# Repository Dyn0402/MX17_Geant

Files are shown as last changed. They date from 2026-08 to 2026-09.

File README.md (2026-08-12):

# MX17 Micromegas Simulation

Geant4 simulation of the MX17/X17 n-TOF Micromegas detector. Multiple geometry
modes support detector development, material budget studies, and calibration.

## Simulation modes

| Mode | `-m` flag | Description |
|---|---|---|
| Vacuum | `vacuum` | Micromegas in vacuum, optional Al upstream shielding |
| Full experiment | `full` | He-3 target → air → MM → PCB → scint wall → 2× LS |
| Sr-90 calibration | `sr90` | Same stack but without He-3 target |
| Sr-90 no-MM | `sr90nomm` | Source in air directly to scint wall → LS (no MM/PCB) |
| LS calibration | `lscalib` | Bare source gun → air → **1 LS layer only** |
| Back scint calibration | `backscintcalib` | Bare source gun → air → **1 back scint bar only** |

The two calibration modes (`lscalib`, `backscintcalib`) study each detector in
isolation with a bare source and are designed to be run with the Sr-90/Y-90
beta spectrum sampled at the gun (`--spectrum`).

## Detector geometry

The MM module (window → support plate) has **one description**,
[`shared/MX17ModuleGeometry.hh`](shared/MX17ModuleGeometry.hh), consumed by
this sim and by `../MX17_Full_Geant`. The default is the **as-built** module
derived from the mechanical CAD + hardware knowledge
([`design/GEOMETRY_FROM_CAD.md`](design/GEOMETRY_FROM_CAD.md),
[`design/GEOMETRY_IMPLEMENTATION_NOTES.md`](design/GEOMETRY_IMPLEMENTATION_NOTES.md);
remaining assumptions in [`design/NEEDED_INPUTS.md`](design/NEEDED_INPUTS.md)):

- **Window**: 60 µm aluminized mylar, 440×440, bulged by the gas overpressure
  (terraced dome, default 8 mm sag ≈ Hencky at ~3 mbar, `--bulge-front`)
- **Window flange**: 5 mm Al ring (440/400.2) = 5 mm gas gap before the cathode
- **Drift**: Cu-clad kapton cathode (406²), 30.000 mm gap set by the Al gas
  frame (440/410), 4× 1.62 mm field-cage PCBs lining the aperture
- **Mesh**: woven SS 19/48 µm → 38 µm effective-density slab (fill 0.223);
  bulk pillars (Ø0.6 mm, 85×85 grid at 4.68 mm) stand in the amplification gap
- **Resistive layer**: 515 discrete ESL strips, 550 µm wide on a 0.8 mm pitch,
  **10 µm** thick over 412²; the 250 µm inter-strip grooves are chamber gas and
  are scored as `AmpGas` (they add 2.0 % of the amp-gas energy deposit)
- **Readout board**: 1.70 mm single body (mesh + 150 µm amp + 10 µm ESL +
  laminate), 470², offset (+15,+15) from the active axis; copper = the five
  physical gerber layers (guard ring, pads, Y strips, X strips, fan-out),
  density-scaled by their measured coverage (`scripts/gerber/analyze_cu_coverage.py`).
  Each layer is built as **two zones** — inside and outside the 399.36 mm
  active window — because the copper is very unevenly distributed: the pad
  layer is 0.76 covered inside the active area and 0.057 outside, so a single
  board-wide average (0.564) would put ~26 % too little copper where the beam
  passes and ~10× too much at the edges. Zoning costs no CPU.
- **Backing**: 5 mm rohacell + 25 µm aluminized mylar + **8 mm Al support
  plate with a 402 mm aperture** concentric with the 399.36 mm active area
- **M1 front-end cards**: 2× per connector edge, flat on the drift side of
  the board edge and straddling it (6.6 mm envelope: 6 gerber Cu layers + FR4)

> **The 399.36 mm active window is metallised, not efficient (2026-08-11).**
> The strip plane is passivated over ~19 mm at each end of **Y**, so the
> efficient area is 399.4 × 359.9 mm, not square. Measured twice (June cosmic
> bench vs the M3 telescope; n_TOF beam run_79 paired clusters —
> `nTof_x17/ntof_active_area/report.html`). Not modelled here on purpose: this
> sim runs at chosen impact points. **Any Y sweep or acceptance number must
> apply the band.** See `design/GEOMETRY_FROM_CAD.md`.

### Real readout pattern (default; `--homogenized-readout` to disable)

The three signal copper layers are built as the **real 512 × 512 pattern** read
off the production gerbers: 0.68 mm square pads on L4, and Ø0.50 mm dots +
0.098 mm bus traces on the L5/L6 X-Y track layers, all on the gerber-exact
0.78 mm pitch. The **ESL resistive layer** is likewise built as 515 discrete
550 µm strips on the 0.8 mm pitch, inside a gas-filled envelope — so the 250 µm
inter-strip grooves are real chamber gas, not reduced-density paste. Total ESL
mass is unchanged (515 × 0.550 / 412 = 0.6875, exactly the old scale factor).

The groove cells are named `AmpGas`, so groove ionisation is scored as
amplification signal: they are only 10 µm deep at the bottom of a 150 µm gap,
so the amplification field runs through them essentially undisturbed. They add
2.0 % of the amp-gas energy deposit.

> ⚠️ **If you consume `ClusterTree`**: the groove cells are thin, so Geant4
> forces short steps and each writes its own row. The grooves are 2.0 % of
> amp-gas *energy* but 21.7 % of amp-gas *rows*. Sum `edep` or `nPrimary` —
> never count rows as a proxy for ionisation. (`nPrimary` is safe: the sub-W
> remainder is carried probabilistically, so nothing is lost to segmentation.)

L3 (guard ring) and L7 (fan-out) have irregular artwork and stay as the
two-zone density-scaled sheets.

Both grids are perfectly regular, so they are built with `G4PVReplica` (two
nested levels for the copper, one for the strips). The whole 786432-feature
copper pattern plus 515 ESL strips costs **17 extra volumes**, not 786943
placements, and cell lookup stays O(1) index arithmetic:

| | volumes | total CPU, 100k sr90 events | max RSS |
|---|---|---|---|
| `--homogenized-readout` | 7342 | 27.0 s | 582 MB |
| patterned (default) | 7359 | 28.0 s | 579 MB |

So the full pattern costs about **+3–4 % of total CPU** and no extra memory.
Removing the fixed ~13 s of startup overlap-checking, the tracking-only cost is
roughly +9 %, most of it from the resist strips rather than the copper (the ESL
is 100 µm thick against 26 µm per Cu layer, and its envelope adds gas/solid
boundaries). Treat these as ±3 % — they were measured as user CPU time,
min-of-4, on a machine with other jobs running.

It is cheap because the patterned layers total ~180 µm of a ~45 mm stack, so
few steps land there — not because the pattern is approximated.

**When you can turn it off**: the signal copper sits *downstream of both gas
gaps*, so for anything scored in the gas the homogenized zones give
essentially the same answer. The resist strips are the part that could matter
even for gas scoring, since the ESL bounds the amplification gap. The pattern
would also get relatively more expensive for tracks at shallow incidence,
which cross many cells per layer.

`--legacy-geometry` is never patterned regardless of these flags, so it stays
bit-identical to the pre-2026-08 output (checked with `scripts/tree_digest.py`).

`--legacy-geometry` restores the pre-2026-08 uniform-slab stack (bit-identical
to the old build). Model figures live in `design/figures/` and regenerate with
`python scripts/model/plot_mx17_model.py`; the cross-section/3D/plan figures
render the **true constructed geometry** from `design/mx17_geometry.json`
(refresh it after geometry changes: `mm_sim -m sr90 --dump-geometry
design/mx17_geometry.json`), while the board/peel figures render the
production gerbers directly.

### The layer stack

Generated from the header — regenerate with `python3 scripts/stack_table.py`,
and `--check` fails if it has drifted from the geometry.

<!-- BEGIN STACK TABLE (generated by scripts/stack_table.py) -->

| Layer | Material | Thickness | G4 volume | Note |
|---|---|---|---|---|
| Gas window | Mylar (PET) | 60 µm | `GasWindow_Mylar` |  |
| Gas window coat | Aluminium | 0.1 µm | `GasWindow_Al` | drift side |
| Window→cathode gas | chamber gas | 5 mm | `WindowGapGas` | set by the 5 mm flange |
| Drift cathode | Kapton | 50 µm | `DriftCathode_Kapton` |  |
| Drift cathode Cu | Copper | 9 µm | `DriftCathode_Cu` | cladding, drift side |
| **Drift gas** ★ | **chamber gas** | 29.991 mm | **`DriftGas`** | kapton back → mesh front = 30.000 mm |
| Micromesh | Stainless steel | 38 µm | `Micromesh` | woven 19/48 µm, fill 0.223 |
| **Amp gas** ★ | **chamber gas** | 150 µm | **`AmpGas`** | bulk pillars Ø0.6 mm on a 4.68 mm grid stand in it |
| Resistive layer (ESL) | C/acrylic paste | 10 µm | `ResistLayer` + `ESLStrip` | 515 strips, 550 µm on 0.8 mm; grooves are `AmpGas` |
| Coverlay kapton | Kapton | 50 µm | `PCB_Kapton` | **the ESL⇄pad insulator** — see the note below |
| Lamination adhesive | Acrylic | 18.8 µm | — *not placed* | response-model estimate, not in the header |
| Cu L3 guard ring | Copper | 26 µm | `PCB_Cu_3` | density-scaled |
| FR4 under L3 | Epoxy-glass | 264.4 µm | `PCB_FR4_3` | **residual** of the CAD 1.70 mm board |
| Cu L4 pads | Copper | 26 µm | `PCB_Cu_4` | real 512×512 pattern |
| FR4 under L4 | Epoxy-glass | 264.4 µm | `PCB_FR4_4` | **residual** of the CAD 1.70 mm board |
| Cu L5 Y strips | Copper | 26 µm | `PCB_Cu_5` | real 512×512 pattern |
| FR4 under L5 | Epoxy-glass | 264.4 µm | `PCB_FR4_5` | **residual** of the CAD 1.70 mm board |
| Cu L6 X strips | Copper | 26 µm | `PCB_Cu_6` | real 512×512 pattern |
| FR4 under L6 | Epoxy-glass | 264.4 µm | `PCB_FR4_6` | **residual** of the CAD 1.70 mm board |
| Cu L7 fan-out | Copper | 26 µm | `PCB_Cu_7` | density-scaled |
| FR4 under L7 | Epoxy-glass | 264.4 µm | `PCB_FR4_7` | **residual** of the CAD 1.70 mm board |
| Rohacell 51 | PMI foam | 5 mm | `PCB_Rohacell` |  |
| Backing mylar | Mylar (PET) | 25 µm | `PCB_BackMylar` | aluminized |
| Backing Al | Aluminium | 0.1 µm | `PCB_AlFoil` |  |
| Support plate | Aluminium | 8 mm | `SupportPlate_Al` | 402 mm aperture |

Depths are in beam order from the window front face; the stack totals **49.835 mm** to the back of the support plate (the readout board body is exactly the CAD **1.700 mm** from mesh front to laminate back). Board **470²**, **399.36 mm** readout window. ★ = scored volume.

**Two cautions about the bottom half of this table.**

*The FR4 is a residual, not a measurement.* The CAD gives one 1.70 mm number for the whole board body; everything we think we know is subtracted and the remainder is divided equally over the five laminate layers. So changing any other layer silently changes the FR4 — when the ESL went 100 → 10 µm the filler went 246.4 → 264.4 µm. A fab stackup drawing would turn this into a real number (`design/NEEDED_INPUTS.md` §6).

*Do not read the ESL⇄pad capacitance off this ordering.* Taken literally the table puts a 264 µm FR4 layer between the coverlay and the pad copper, because the guard-ring layer above the pads is placed first — and that layer has **zero** copper inside the active window, so the separation there is an artifact of the equal-division residual above, not geometry anyone measured. The response model instead takes the physically motivated adjacency for a resistive Micromegas: the ESL sits on the coverlay kapton, which is laminated straight onto the pads. That is the stack `response/solver/wpot.py` solves, and the ~19 µm of adhesive is 29 % of the insulator it sees. The two models disagree here and the disagreement is unresolved; it does not matter for material budget (order barely matters for energy deposit) and it matters completely for the induced signal. The same missing fab drawing settles both.

<!-- END STACK TABLE -->

Everything downstream of the module is unchanged:

- **He-3 target**: r = 1.5 cm, L = 8 cm, 300 bar; Al (0.5 mm) + CFRP (0.9 mm) capsule
- **Trigger scint wall**: 200 µm BlackMylar tape + 3 mm PVT + 50 µm Al foil
- **LS stack**: 2 mm CFRP wall + 600 µm inner CFRP liner + 40 µm Al liner + **2 cm LAB** × 2 layers
- **Back scint bar**: 30×20×2 cm PVT, wrapped in 20 µm Al foil + 200 µm BlackMylar tape

## Command-line options

```
-m <mode>          vacuum | full | sr90 | sr90nomm | lscalib | backscintcalib
-p <particle>      electron | gamma | positron | proton | muon | ...
-e <energy>        Particle energy [MeV]  (ignored when --spectrum is set)
-n <nevents>       Number of events
-g <gas>           ArIso | ArCF4 | ArCO2 | HeEth | NeCF4 | PureAr | ...
-o <output>        Output file base name
-s <seed>          Random seed
-t <nthreads>      MT threads (default: 1)
-c <mm>            CFRP wall thickness [mm] (default: 2.0)
--spectrum <csv>   Sample electron energies from Sr-90/Y-90 spectrum CSV
                   (two whitespace-separated columns: energy_MeV  probability)
--src-dist <mm>    Source-to-detector air gap [mm] (lscalib/backscintcalib, default: 100)
--bulge-front <mm> Front-window overpressure dome sag (default: 8, 0 = flat)
--legacy-geometry  Pre-2026-08 uniform-slab MM module (old stack, bit-identical;
                   never patterned, regardless of the flags below)
--homogenized-readout  Density-scaled copper sheets + ESL slab instead of the
                   default real pattern (~3 % faster; see "Real readout pattern")
--patterned-readout Explicitly request the real pattern (this is the default)
--dump-geometry <f> Write the constructed geometry to JSON and exit (feeds
                   scripts/model/plot_mx17_model.py so figures show the true geometry)
-v                 Verbose
-h                 Help
```

## Output columns

**All modes** (`_events.csv`): `eventID, edepDrift_eV, edepAmp_eV, ...`

**Full / Sr90 modes** (extra columns):
```
edepHe3Gas, edepMylar, edepCathode, edepMicromesh,
edepPCB, edepPCBKapton, edepPCBCu, edepPCBFR4, edepPCBRohacell, edepPCBAlFoil,
edepScintWall, edepScintTape, edepScintAlFoil,
edepLS1_eV, edepLS2_eV, edepLSCFRP_eV,
primInHe3Gas, primInPCB, primInScintWall, primInLS1, primInLS2, primInLSCFRP5
```

**kLSCalib / kBackScintCalib** (extra columns):
```
primaryKE_MeV,          ← sampled beta energy
edepLS1_eV,             ← energy in LAB layer  (lscalib)
edepLSCFRP_eV,          ← energy in LS structural walls (lscalib)
primInLS1,
edepBackScint_eV,       ← energy in PVT bar  (backscintcalib)
primInBackScint
```

## Building on lxplus

```bash
ssh lxplus.cern.ch
source scripts/setup_lxplus.sh
bash scripts/build.sh
```

The binary is written to `build/mm_sim`.

## Running on lxplus with HTCondor

> **AFS vs EOS rule**: HTCondor's submit file (`executable`, `log`, `output`, `error`)
> must reference AFS paths. Simulation output files are written by the job script and
> may live on EOS. Each submit script enforces this automatically:
> `--jobdir` (AFS, default `~/condor/...`) controls job control files;
> `--outdir` (EOS) controls where ROOT/CSV output is written.

### Sr-90 calibration (full material stack, energy sweep)

```bash
python scripts/submit_condor_sr90.py \
    --exe /eos/home-d/dneff/sim/mm_sim \
    --outdir /eos/home-d/dneff/sim/sr90_out \
    --mode sr90nomm
# jobdir defaults to ~/condor/mx17_geant_sr90 (AFS)
```

### LS calibration (liquid scintillator only, Sr-90 spectrum sampling)

```bash
python scripts/submit_condor_lscalib.py \
    --exe      /eos/home-d/dneff/sim/mm_sim \
    --spectrum /eos/home-d/dneff/sim/sr90_calibration/Sr90_Y90_Beta_Spectrum.csv \
    --outdir   /eos/home-d/dneff/sim/lscalib_out \
    --mode ls --njobs 20 --nevents 100000
# jobdir defaults to ~/condor/mx17_lscalib (AFS)
```

### Back scint calibration (plastic scint only, Sr-90 spectrum sampling)

```bash
python scripts/submit_condor_lscalib.py \
    --exe      /eos/home-d/dneff/sim/mm_sim \
    --spectrum /eos/home-d/dneff/sim/sr90_calibration/Sr90_Y90_Beta_Spectrum.csv \
    --outdir   /eos/home-d/dneff/sim/backscint_out \
    --mode backscint --njobs 20 --nevents 100000
```

### Merging job outputs

```bash
# ROOT (if built with USE_ROOT)
hadd lscalib_all.root lscalib_out/ls_calib_job*.root

# CSV
head -1 lscalib_out/ls_calib_job000_events.csv > ls_merged.csv
tail -n +2 -q lscalib_out/ls_calib_job*_events.csv >> ls_merged.csv
```

### Full experiment (X17 physics, energy sweep)

```bash
python scripts/submit_condor_full.py \
    --exe /eos/home-d/dneff/sim/mm_sim \
    --outdir /eos/home-d/dneff/sim/full_out
```

## Analysis

### LS / back scint calibration

```bash
# After merging job outputs:
python ls_calibration/analyze_ls_calibration.py \
    --indir /path/to/merged --mode ls   --outpdf ls_calib.pdf

python ls_calibration/analyze_ls_calibration.py \
    --indir /path/to/merged --mode backscint --outpdf backscint_calib.pdf
```

Output PDF contains:
- Edep spectrum (all events + zoom)
- Mean edep and efficiency vs sampled beta energy
- 2D: beta energy vs detector edep
- Summary page with spectrum-integrated statistics

### Sr-90 calibration analysis (full material stack)

```bash
python sr90_calibration/analyze_sr90_calibration.py \
    --indir /path/to/sr90nomm/csvs --prefix sr90nomm
```

### Full experiment analysis

```bash
python scripts/analyze_full_experiment.py \
    --indir /path/to/full/csvs --gas ArIso --prefix full
```

## Calibration geometry details

### kLSCalib

```
Gun position (z = −totalZ/2)
↓  [100 mm air, configurable via --src-dist]
LS_CFRP_1       2 mm   CFRP structural front wall
LS_InnerCFRP_1  600 µm inner CFRP liner
LS_Al_1         40 µm  Al liner
LiqScint_1      20 mm  LAB liquid scintillator  ← scored: edepLS1
LS_InnerCFRP_2  600 µm
LS_Al_2         40 µm
LS_CFRP_2       2 mm   CFRP structural back wall
```

### kBackScintCalib

```
Gun position (z = −totalZ/2)
↓  [100 mm air, configurable via --src-dist]
BackScintWrap_Tape1   200 µm  black mylar tape
BackScintWrap_Al1      20 µm  Al foil
BackScint              20 mm  PVT plastic scintillator  ← scored: edepBackScint
BackScintWrap_Al2      20 µm
BackScintWrap_Tape2   200 µm
```

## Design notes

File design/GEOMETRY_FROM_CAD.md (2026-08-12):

# MX17 as-built geometry vs. the Geant4 models

Derived from the mechanical CAD on 2026-08-06. This is a reference for updating
`src/DetectorConstruction.cc`; it states what the CAD says, what the two
simulations said at the time, and where they disagreed.

> **Status 2026-08-06 (later the same day):** the as-built geometry below is
> now implemented in `shared/MX17ModuleGeometry.hh` (consumed by both sims);
> the ❌ marks in the side-by-side table describe the *pre-upgrade* models and
> are kept as the historical record. See
> [`GEOMETRY_IMPLEMENTATION_NOTES.md`](GEOMETRY_IMPLEMENTATION_NOTES.md) for
> what was done and [`NEEDED_INPUTS.md`](NEEDED_INPUTS.md) for the remaining
> assumptions. Model figures: `design/figures/mx17_*.png`
> (`scripts/model/plot_mx17_model.py`).
>
> **Correction:** discrepancy 1 below originally claimed the 8 mm support
> plate is solid. That was a parser error — see the rewritten entry.

## Sources

| Source | Location | Notes |
|---|---|---|
| Full detector CAD | `~/x17/mx17_cad/MX17 2026 v1.3 05 06 2026.stp` | 14 MB, Solid Edge → STEP AP214, exported 2026-06-05. 23 products, 72 placed instances. **One** MX17 module. |
| PCB fabrication data | `design/gerbers/` (in this repo) | Readout gerbers; `DFS3498A_gasframe.gbr` independently confirms the frame aperture. |
| LS vessel | `~/x17/LS_Stuff/LS X17.step` | Shapr3D, separate file. Already modelled in `MX17_Full_Geant`. |
| Scintillator clamps | `~/x17/mx17_cad/assembly of scintillators.stp` | 4× `pince scintillateur` only; its `LS X17` children are empty placeholders. |
| Trigger paddle / PMT | `~/x17/mx17_cad/paletta_e_supportoPM.stp` | `paletta` 200×24×492, `supporto_XP2982_v2` (Photonis XP2982). Not part of the MM stack. |

## As-built stack

Along the beam axis, entrance first. Dimensions in mm, measured from the solids.

| Z range | Part | Transverse | Thickness |
|---|---|---|---|
| 307.897–307.957 | Mylar window | 440 × 440 | 0.060 |
| 302.897–307.897 | **window flange** (Al ring) | 440 outer, 400.2 aperture | 5.000 |
| 302.847–302.897 | Kapton drift cathode | 406 × 406 | 0.050 |
| 272.847–302.847 | **Alu gas flange** (the frame) | 440 outer, **410.0 aperture**, 15 mm wall | **30.000** |
| 272.847–304.447 | 4× drift field PCB (field cage) | 408.4 × 1.62, forming a 410 mm ring | 31.6 tall |
| 271.247–272.947 | PCB readout | 470 × 470 | 1.700 |
| 266.247–271.247 | rohacell | 470 × 470 | 5.000 |
| 258.247–266.247 | **Alu detector support** | 470 × 470, **402 × 402 through-aperture** | 8.000 |

Also present, outside the beam path: 4× `multi M1 PCB` (41 × 180 × 6.6) forming a
446 mm ring around the readout, the SHV/HV housing and covers, gas entry fittings,
geometer targets and fasteners.

Key derived numbers:

- **Drift gap = 30.000 mm exactly** — the Al frame *is* the spacer; its faces
  coincide with the readout PCB top and the Kapton cathode.
- **Frame aperture 410.0 mm** — cross-checked against `DFS3498A_gasframe.gbr`,
  whose routing outline runs ±205 mm. Two independent files agree.
- Window face to readout surface: **35.010 mm** (sim: 30.379 mm).
- Total module depth, Mylar front to Al support back: **49.710 mm** (sim: 35.983 mm).
- Material behind the gas, **on axis**: **6.70 mm** (1.70 PCB + 5.00 rohacell;
  the 8 mm Al plate has a 402 mm aperture clearing the active area) vs
  **5.604 mm** in both sims. Outside the aperture the plate adds its 8 mm.

## Side-by-side

`MX17_Geant` = this repo (`src/DetectorConstruction.cc`).
`MX17_Full_Geant` = `../MX17_Full_Geant/src/DetectorConstruction.cc`.
The two use **identical** MM and PCB layer constants; they differ only in
transverse face size and in that Full_Geant replicates the module across 4 arms.

| # | Feature | As-built (CAD) | MX17_Geant | MX17_Full_Geant |
|---|---|---|---|---|
| 1 | Mylar window | 60 µm, 440×440 | ❌ 40 µm | ❌ 40 µm |
| 2 | Window Al metallization | 🔶 absent from CAD | ✅ 0.1 µm | ✅ 0.1 µm |
| 3 | Window flange (Al ring, 5 mm) | present | ❌ absent | ❌ absent |
| 4 | Gas gap, window → cathode | 5.0 mm | ❌ absent | ❌ absent |
| 5 | Kapton drift cathode | 50 µm, 406×406 | ✅ 50 µm | ✅ 50 µm |
| 6 | Cu cathode cladding | 🔶 absent from CAD | ✅ 9 µm | ✅ 9 µm |
| 7 | **Drift gap** | **30.000 mm** | ✅ 30 mm | ✅ 30 mm |
| 8 | **Aluminium gas frame** | 440 out / 410 ap / 30 mm | ❌ absent | ❌ absent |
| 9 | Drift field-cage PCBs | 4× 408.4×1.62×31.6 | ❌ absent | ❌ absent |
| 10 | Micromesh | ⚠️ inside 1.7 mm board | ⚠️ 30 µm slab | ⚠️ 30 µm slab |
| 11 | Amplification gap | ⚠️ inside 1.7 mm board | ⚠️ 150 µm | ⚠️ 150 µm |
| 12 | Resistive paste | ⚠️ inside 1.7 mm board | ⚠️ 100 µm | ⚠️ 100 µm |
| 13 | Readout PCB body | 1.70 mm, 470×470 | ❌ 0.554 mm laminate | ❌ 0.554 mm laminate |
| 14 | Rohacell | 5.0 mm, 470×470 | ✅ 5 mm | ✅ 5 mm |
| 15 | **Backing plate** | **8 mm Al ring, 402 mm aperture** | ❌ 50 µm Al foil | ❌ 50 µm Al foil |
| 16 | Front-end (multi M1) PCBs | 4× 41×180×6.6 | ❌ absent | ❌ absent |
| 17 | Transverse face | 440 (window) / 470 (PCB) | ⚠️ 400 × 400 | ⚠️ 380 × 340 |
| 18 | Copper readout segmentation | pads + X/Y strips | ❌ solid Cu sheets | ❌ solid Cu sheets |
| 19 | Material behind gas | 14.70 mm | ❌ 5.604 mm | ❌ 5.604 mm |
| 20 | Aluminized mylar behind rohacell | 🔶 absent from CAD | ❌ absent | ❌ absent |
| 21 | Front-window pressure bulge | n/a (CAD is unpressurized) | ❌ flat | ❌ flat |

✅ matches · ❌ disagrees · 🔶 real, but absent from the CAD · ⚠️ not determined
by the CAD, or approximated by choice

Rows 2, 6, 20 and 21 come from Dylan's knowledge of the hardware, not from the
files. The mechanical CAD models foils as plain solids and carries no
metallization or cladding, so its silence on rows 2 and 6 is not evidence of
absence — **the simulations are right there and must not be "corrected" toward
the CAD.** See [`GEOMETRY_IMPLEMENTATION_NOTES.md`](GEOMETRY_IMPLEMENTATION_NOTES.md) §2.

## Discrepancies, worst first

**1 — The 8 mm aluminium backing plate is missing (row 15).**
`Alu detector support modifié` is a 470 × 470 × 8 mm plate directly behind the
rohacell — **with a 402 × 402 mm square through-aperture** (plus ~100
bolt/fastener holes of r ≤ 2.5 mm at the periphery).

*Correction 2026-08-06:* this entry originally claimed the plate was "verified
solid". That was wrong — the first STEP parse missed the inner boundary loops
of the two Z-normal faces. Re-analysis of the face loops shows an inner
FACE_BOUND of 402 × 402 mm on both faces (a through-cut), offset (−15, −15) in
the part frame. Cross-registration with the readout gerbers
(`DFS3498A_activearea.gbr`: 399.36 mm active area flashed at the gerber
origin; copper extents centred (+15, +15)) shows the **aperture is concentric
with the active area** — 1.32 mm clearance per side — and it is the 470 mm
plates (readout PCB, rohacell, support plate) that sit offset (+15, +15) from
the active axis. Dylan confirmed the intent: the frame screws into the plate,
but there is no aluminium behind the active area.

So the plate does *not* block on-axis Sr-90 betas; it matters for the
periphery (frame-region scattering and anything outside the 402 mm square).
Both sims previously modelled this position as 50 µm of Al foil over the full
face — wrong in both directions at once.

**2 — Material behind the gas: 14.70 mm vs 5.604 mm (row 19).**
Even setting the Al plate aside, the readout board is a single 1.70 mm solid in
CAD where the sims build a 0.554 mm laminate of 4×(26 µm Cu + 100 µm FR4) plus
50 µm Kapton.

**3 — Missing 5 mm gas gap between window and cathode (row 4).**
The window flange is 5 mm thick with a 400.2 mm aperture; the Mylar sits on its
outer face, the Kapton on its inner face. The gap between them is open gas. Both
sims stack Mylar → Al → Kapton → Cu contiguously.

**4 — Mylar window 60 µm, not 40 µm (row 1).**

**5 — All lateral structure absent (rows 3, 8, 9, 16).**
The 30 mm Al frame ring, the 5 mm window flange ring, the field cage and the
front-end boards. Irrelevant for on-axis transmission; this is exactly the
material that governs peripheral scattering and frame-induced background.

## What the CAD does *not* settle

- **Materials.** STEP carries no material assignment. "Aluminium" for the frame,
  window flange and support plate comes from part names only.
- **Mesh, amplification gap, resistive paste.** Absent as separate solids — they
  are sub-mm bulk-process features folded into the 1.70 mm `PCB readout` body.
  The sims' separate layers are not contradicted; in reality they live inside
  that 1.7 mm. Do not add their thickness on top of the CAD numbers.
- **PCB internal stackup.** Copper and dielectric thicknesses are in neither the
  CAD nor the gerbers. The 26 µm / 100 µm values in the sims have no traced
  source. The gerbers do give in-plane segmentation: 0.68 mm pads on 0.78 mm
  pitch, 512 × 512 over a 399.36 mm active area, with 3 functional copper layers
  (pads, Y strips, X strips) — not the 4 uniform sheets both sims use.
- **The Y-edge passivation** (added 2026-08-11). The gerbers' 399.36 mm active
  area is the *metallised* region, and this sim builds exactly that, square. But
  the strip plane is **passivated over a ~19 mm band at each end of the Y
  coordinate**, so a particle landing there produces no collected charge at all
  — neither plane sees it. The efficient region is therefore
  **399.4 mm in X × 359.9 ± 1.8 mm in Y**, not square.

  Measured twice, agreeing to 1–2 mm: June 2026 cosmic bench against the M3
  telescope (all five chambers, `nTof_x17/common/mx17_active_area.py`), and
  n_TOF beam run_79 paired strip clusters with no external reference (chambers
  A/B/C, `nTof_x17/ntof_active_area/report.html`). The band is centred.

  **Likely mechanism, not measured:** `RESPONSE_SIM_PLAN.md` §1 records that the
  ESL resistive strips contact copper bus strips **at both y-ends of the active
  area and nowhere in between** (user, 2026-08-07). A dead band of the same
  width, at the same two ends, on the same coordinate, is what a covered bus
  termination would look like. That would explain why the passivation is on Y
  and not X, which is otherwise an odd asymmetry. Nobody has checked it against
  the gerbers — if the bus footprint is ~19 mm, this is closed.

  **This sim does not model it, deliberately.** The pad/strip structure here is
  the readout geometry and is validated as such; the passivation is a collection
  effect on top of it, and adding it would change the pad build for no gain in
  the response chain, which is run at chosen impact points rather than over a
  flood. **But any study that sweeps the impact point across the full Y range,
  or that quotes an area or an acceptance, has to apply the band itself.** In
  `MX17_Full_Geant` — where the sim *is* used for acceptance — it is applied,
  as `mm_size_v_cm = 36.0`.

## Method

Bounding boxes and placements were extracted with a purpose-written STEP parser.
Two traps, both of which produce plausible-looking wrong answers:

1. **Bounding boxes must use `VERTEX_POINT`s only.** Taking every
   `CARTESIAN_POINT` includes arc and fillet centres that lie far outside the
   solid — the gas frame measured 931 × 927 × 598 mm instead of 440 × 440 × 30.
2. **Assembly transform direction must be resolved, not assumed.** Match
   `REPRESENTATION_RELATIONSHIP.rep_1/rep_2` against the child product's own
   shape representation to decide which `ITEM_DEFINED_TRANSFORMATION` item is
   the child frame. With the convention reversed, the four field-cage PCBs
   scatter ~2 m apart instead of closing into their 410 mm square.

Sanity checks that passed: the four field-cage PCBs close into a 410.0 mm ring;
the four front-end boards close into a 446 mm ring; the frame aperture matches
the gerber gas-frame outline; all plate thicknesses come out as round numbers.

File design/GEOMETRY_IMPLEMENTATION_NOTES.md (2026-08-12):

# MX17 geometry — implementation brief

Companion to [`GEOMETRY_FROM_CAD.md`](GEOMETRY_FROM_CAD.md), which records the
as-built dimensions. This file is the **work order**: what to change, in what
order, and which numbers are still missing.

Written 2026-08-06. Items 2–5 come from Dylan's domain knowledge and correct or
extend what the CAD alone shows.

> **Status — implemented 2026-08-06.** All six tasks are done:
>
> - §1 merge: `shared/MX17ModuleGeometry.hh` is the single module description,
>   consumed by both repos (option A, relative-path include with a CMake
>   guard). Landed as a pure refactor first — fixed-seed runs of every mode in
>   both sims were verified **bit-identical** to the pre-refactor builds.
> - §2–§6 applied on top: 60 µm window, 5 mm flange gap, copper-clad cathode,
>   440/406/410/470 faces + rings + field cage + M1 cards, woven-mesh
>   effective-density slab (19/48 µm placeholder), 1.70 mm readout body,
>   aluminized-mylar back foil (25 µm assumed), 8 mm support plate, terraced
>   front-window bulge (8 mm sag ≈ Hencky at 3 mbar, `--bulge-front`).
>   `--legacy-geometry` restores the old stack.
> - The §6 "held back" item is resolved: the plate has a **402 mm aperture in
>   the STEP file** (the earlier "verified solid" reading was a parser error —
>   see `GEOMETRY_FROM_CAD.md`, discrepancy 1) so it is modelled as a ring and
>   does not stop on-axis betas.
> - Remaining assumptions moved to [`NEEDED_INPUTS.md`](NEEDED_INPUTS.md).
> - Python mirror + figures: `scripts/model/`, output in `design/figures/`.

## Task summary

| # | Task | Blocked on input? |
|---|---|---|
| 1 | Merge the two Geant4 detector descriptions into one source of truth | no |
| 2 | Correct the CAD reading: drift copper and window aluminization | no |
| 3 | Add the aluminized mylar behind the rohacell | **yes** — thicknesses |
| 4 | Port the gas-pressure bulge on the front mylar from `p2_geant` | **yes** — overpressure |
| 5 | Port the woven-micromesh model from `p2_geant` | **yes** — mesh spec |
| 6 | Apply the CAD corrections from `GEOMETRY_FROM_CAD.md` | partly — see §6 |

---

## 1. Merge the two models

`MX17_Geant/src/DetectorConstruction.cc:206-224` and
`MX17_Full_Geant/src/DetectorConstruction.cc:193-208` currently declare the
**same MM and PCB layer constants twice**, value for value — 40 µm Mylar,
0.1 µm Al, 50 µm Kapton, 9 µm Cu, 30 mm drift, 30 µm mesh, 150 µm amp,
100 µm resistive paste, then 50 µm Kapton + 4×(26 µm Cu + 100 µm FR4) +
5 mm rohacell + 50 µm Al. Every geometry fix below therefore has to be applied
twice, and the two will drift apart the first time someone forgets.

**Goal:** one description of the MX17 module, consumed by both.

What must stay configurable per consumer (these legitimately differ):

| Property | MX17_Geant | MX17_Full_Geant |
|---|---|---|
| Transverse face | 400 × 400 mm | ~~380 × 340~~ → **399 × 360 mm** (`mm_size_u_cm`, `mm_size_v_cm`; measured 2026-08-11, see below) |
| Instances | 1, on axis | 4 arms, pinwheel-shifted |
| Local axes | z along beam | (u, v, w) per arm |
| Modes | 6 `SimMode` variants | full-experiment only |

Suggested shape: a header-only `MX17ModuleGeometry.hh` exposing a thickness
struct plus a `BuildModule(...)` that takes half-width, half-height and a
placement lambda, so each caller keeps its own transverse size and placement
convention. Two ways to share it across the repos:

- **A shared header referenced by relative path** in the second repo's
  `CMakeLists.txt`. Simplest; fragile if the sibling checkout moves.
- **A copy kept in sync by script**, with the header carrying a checksum
  comment. Uglier, but survives independent checkouts.

Recommend A, with a CMake `if(NOT EXISTS ...)` guard giving a clear error.

**Do the merge as a pure refactor first.** Land it with the geometry numerically
unchanged, confirm both sims produce identical output to the current build, and
only then start applying §2–§6. Mixing a refactor with physics changes makes a
regression impossible to attribute.

---

## 2. Corrections to the CAD reading

Two places where **the CAD is incomplete and the simulations are right**. Do not
"fix" the sims toward the CAD here.

| Item | CAD shows | Reality | Action |
|---|---|---|---|
| Drift cathode copper | `Kapton drift`, 50 µm, bare | Kapton is **copper-clad** | Keep `tCuCath = 9 µm`. CAD omission. |
| Window aluminization | `Mylar window`, 60 µm, bare | Mylar is **aluminized** | Keep `tAlWin = 0.1 µm`. CAD omission. |

The mechanical CAD models foils as plain solids and simply does not carry
metallization or cladding. Rows 2 and 6 of the comparison table in
`GEOMETRY_FROM_CAD.md` have been updated accordingly.

Still to confirm: which **side** each metal layer faces. The current stacking
order (Mylar → Al → Kapton → Cu → drift gas) puts both metals on their
drift-facing side, which is the physically sensible reading, but it is an
assumption. `p2_geant` hit the same question and resolved it explicitly for the
P2 cathode — see `p2_geant/docs/P2_MODEL.md`, "Al on gas side **confirmed**".

The 60 µm Mylar thickness from the CAD **does** stand — that is a mechanical
dimension, and it supersedes the 40 µm in both sims.

---

## 3. New layer: aluminized mylar behind the rohacell

Missing from the CAD **and** from both simulations. There is a second aluminized
mylar foil on the **back face of the rohacell**.

Proposed placement in the stack, after `PCB_Rohacell` and before the 8 mm
aluminium support plate:

```
... PCB_Rohacell (5 mm)
    RohacellBack_Mylar   <- thickness TBC
    RohacellBack_Al      <- thickness TBC, side TBC
    AluSupportPlate (8 mm, see GEOMETRY_FROM_CAD.md §Discrepancies)
```

**Needed before implementing:**

- mylar thickness (µm)
- aluminization thickness (µm) — 0.1 µm if it matches the window
- which side the aluminium faces
- transverse extent — assume 470 × 470 to match the rohacell unless told otherwise

Note this replaces, conceptually, what both sims currently call `PCB_AlFoil`
(50 µm Al). That 50 µm slab appears to be a stand-in for exactly this foil,
guessed rather than measured. It is **not** the 8 mm support plate. Resolve
whether the 50 µm should become this aluminized mylar, with the 8 mm plate added
separately behind it.

---

## 4. Front-window bulge from gas overpressure

Reference implementation: `p2_geant/src/DetectorConstruction.cc:870-908`
(`BuildWindow` lambda), documented in `p2_geant/docs/P2_MODEL.md` under
"Window bulge model".

### The p2_geant approach

A **terraced dome**: `N = 6` stacked gas prisms whose outline shrinks about the
opening centroid on a spherical-cap profile, each step capped by a flat mylar
ring, the last step a full cap.

```cpp
for (int k = 0; k <= N; ++k) {
    const double a = k * M_PI / (2.0 * N);
    sig[k] = std::max(std::cos(a), 0.04);   // lateral shrink factor
    h[k]   = H * std::sin(a);               // height of step k
}
```

Step `k` places a gas prism of outline `ScaleAbout(opening, centroid, sig[k])`
and height `h[k+1] - h[k]`, then a mylar terrace on top of it — an annulus
(`outline[k]` minus `outline[k+1]`) for `k < N-1`, a full cap for the last.

The property that makes this work: **every vertical path through the dome
crosses exactly one mylar thickness.** A naive nested-shell dome would
double-count material near the rim, which is precisely where a bulge changes the
path length. Preserve this property in any reimplementation.

`sign = -1` builds the dome rising upstream (front window); `+1` downstream.
MX17 needs only the front window — the readout PCB is the downstream gas
boundary, so there is no back window to bulge.

### Adapting to MX17

The p2 code extrudes an arbitrary wedge polygon via a `Prism` helper
(`p2_geant/src/DetectorConstruction.cc:851`) because the P2 opening is a wedge.
**MX17's opening is a plain 410 × 410 mm square** — the aluminium gas frame
aperture. So the polygon machinery collapses: use `G4Box` for the gas steps and
`G4Box` minus `G4Box` (`G4SubtractionSolid`) for the mylar annuli, scaling the
half-widths by `sig[k]` about the centre. Simpler and cheaper than
`G4ExtrudedSolid`.

### Sag height — must be computed, not copied

`p2_geant` uses `p2_bulge_front_mm = 10.0` from a Hencky estimate at ~3 mbar,
with the comment that 1–10 mbar spans 7–15 mm. **Do not carry that number over.**
Hencky sag scales with the membrane radius, and MX17's 410 mm square aperture is
substantially larger than the P2 wedge opening, so the same overpressure gives a
materially larger sag. Recompute for MX17's aperture, foil thickness (60 µm) and
actual operating overpressure.

Expose it as a config knob (`mx17_bulge_front_mm`) so it can be scanned, exactly
as p2 does.

**Needed:** operating overpressure, and confirmation of the Mylar elastic
modulus / foil pre-tension assumptions if a Hencky estimate is used.

---

## 5. Micromesh as a woven-mesh effective-density slab

Reference implementation: `p2_geant/src/DetectorConstruction.cc:777-791`.

Both MX17 sims currently model the mesh as a **30 µm slab of solid stainless
steel at full density** — a mesh is mostly holes, so this overstates its mass.

The p2 model replaces it with a slab of density-scaled steel whose areal mass
matches the real weave:

```cpp
const G4double dWire     = wire_diameter;
const G4double meshPitch = dWire + opening;
const G4double tMesh     = 2.0 * dWire;               // weave height
const G4double meshFill  = M_PI * dWire / (4.0 * meshPitch);
matMesh = new G4Material("MeshSteelEff", matSteel->GetDensity() * meshFill, 1);
matMesh->AddMaterial(matSteel, 1.0);
```

The fill fraction comes from the steel volume per unit area of a plain weave
with two orthogonal wire sets, `π·d²/(2p)`, divided by the slab thickness `2d`.

For P2's 48 µm opening / 19 µm wire: pitch 67 µm → 38 µm slab at fill 0.223.

**Scale of the correction:** a 30 µm solid-steel slab carries ≈ 0.024 g/cm²;
a P2-like weave carries ≈ 0.0068 g/cm². If MX17's mesh is a comparable weave,
the current model overstates mesh material by roughly a factor of 3.5.

Caveat to carry over in the comment: this reproduces the **material budget
only**. Optical transparency — `(opening/pitch)²`, ≈ 51 % for the P2 weave — is
not geometrically modelled, so the mesh does not shadow anything.

**Needed:** the MX17 mesh spec (wire diameter and opening, or the weave
designation). Also worth confirming the amplification gap while asking: both
sims use 150 µm, a bulk Micromegas is often 128 µm, and the CAD folds it
invisibly into the 1.70 mm readout board.

---

## 6. Applying the CAD corrections

From `GEOMETRY_FROM_CAD.md`. Straightforward once §1 lands:

- Mylar window 40 → 60 µm
- Add the 5 mm gas gap between window and cathode (window flange aperture 400.2 mm)
- Readout PCB laminate 0.554 → 1.70 mm single body
- Transverse faces: 440 mm at the window, 470 mm at the PCB
- Lateral structure: 30 mm Al frame ring (440 outer / 410 aperture), 5 mm Al
  window-flange ring, 4× field-cage PCB, 4× front-end board

**Held back pending confirmation:** the 8 mm aluminium backing plate. It stops
Sr-90 betas outright, so adding it changes what `kSr90Calibration` and
`kFullExperiment` predict downstream. Confirm it is in the beam path for the
runs being simulated before implementing — see `GEOMETRY_FROM_CAD.md`,
discrepancy 1.

---

## Inputs still needed

| # | Input | Blocks | Resolution (2026-08-06) |
|---|---|---|---|
| 1 | Rohacell-back mylar: mylar µm, Al µm, which side | §3 | **assumed** 25 µm + 0.1 µm Al (Dylan: use as placeholder) |
| 2 | Is the 50 µm `PCB_AlFoil` meant to be that foil? | §3 | **yes** — replaced by the aluminized mylar |
| 3 | Operating gas overpressure | §4 | **assumed** ~3 mbar → 8 mm sag (`--bulge-front`) |
| 4 | Micromesh wire Ø and opening | §5 | **placeholder** P2 weave 19/48 µm |
| 5 | Amplification gap: 150 µm or 128 µm | §5 | open — 150 µm kept |
| 6 | Which side the window Al and cathode Cu face | §2 | open — drift-facing assumed |
| 7 | Is the 8 mm Al support plate in the beam path? | §6 | **resolved** — plate has a 402 mm aperture in the STEP; modelled as a ring |
| 8 | PCB internal stackup (Cu/dielectric thicknesses) | §6 | open — historical Cu kept, FR4 filler solved to the 1.70 mm body |

Live register: [`NEEDED_INPUTS.md`](NEEDED_INPUTS.md) (modeled on
`p2_geant/docs/NEEDED_INPUTS.md`).

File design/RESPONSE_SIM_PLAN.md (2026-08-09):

# MX17 Full Detector-Response Simulation — Implementation Plan

**Status:** IN IMPLEMENTATION — the chain runs end to end and wft reads its output unmodified. See §0a for the state of play, what is certified, what is next, and the open problems. **Date:** 2026-08-06, last updated 2026-08-09.
**Authority:** this document. Where it conflicts with older notes, this wins. Update it as decisions land ("living document").
**Audience:** an implementing agent/developer who has NOT read the research behind this plan. Every stage gives the equation or the reference, the file contract, the host to run on, and acceptance criteria. When something is genuinely open, it is listed in §12 with the default to proceed with — do not block on §12 items.

~~**Coordination rule:** a parallel effort is updating the Geant4 geometry; until it merges, do NOT edit existing C++ files.~~ **The geometry work has merged (2026-08-07)** and Stage A is done (T8). A parallel effort may still be active in this repo — check `git log` before editing C++.

---

## 0a. STATE OF PLAY — read this first (updated 2026-08-10; earlier snapshots below are 2026-08-09, 2026-08-08 and 2026-08-07)

### 2026-08-10 update — the ion term IS the rise discrepancy, the amplitude ledger closes to ONE candidate, and the ion contradiction is now structurally cornered

Overnight worker, 2026-08-09 → 08-10. Full record `design/report/OVERNIGHT_2026-08-10.md`;
five-minute version `design/report/MORNING_BRIEF_2026-08-10.md`.

**The rise discrepancy is the ion term, measured across the whole distribution.**
Previously this rested on p5 of a single vertical sample. At 10° and 20° the ion
term is a **near-rigid ~95 ns delay at every quantile**, the data needs ~75 of
those removed, and removing it entirely slightly overshoots (−10 ns at 10°,
−24 at 20°). **The data's rise is reproduced at f_eff ≈ 0–0.25 on six quantiles
at two independent inclinations**, against the defended f_ion = 0.9056. Nothing
was fitted — the DIAGNOSIS legs already existed and were read at matched
quantiles. **Track inclination is eliminated** as the explanation, and
`ANGLED_LADDER_2026-08-09.md` §4's "the sim barely responds to inclination" is
**WITHDRAWN** — a 200 ns threshold artifact sitting below the sim's own floor
(at 240 ns the sim goes 0.045 → 0.749 over 0–20°). Its open thread #4 is also
tested and answered **NO**: cutting the vertical leg on |θ_other| < 3° moves the
offset span by +1 ns (X) / −4 ns (Y), so the vertical broadening is real, not a
one-view-window artifact — measure the rise offset at INCLINED points.

**The amplitude ledger has exactly one surviving candidate.** Quote the deficit
in CHARGE: `q_sum` is **f_ion-invariant** (0.626–0.642 across the whole f_ion
range), so the ×0.63 charge deficit cannot be double-counted against the ion
thread. It demands a gain of **~4 × 10⁴ against the sim's 24 094 (×1.6)**, and
an independent re-measurement off the raw HV-scan calib gives a slope error of
**sim 0.3106 ± 0.0033 vs data 0.4487 ± 0.0093 per 10 V (×1.44)**. Both rows that
owed numbers are now closed: **primary ionisation is measured and correct**
(91.2 e⁻/cm, W = 25.97 eV, 3.83 e⁻/cluster — cannot carry ×1.6) and diffusion
dilution cannot touch an integral. **A single α(E)/Penning error at the
operating point would produce both numbers, and neither was derived from the
other.** The T7 slope hunt is the test; its decision rule is pre-registered in
`response/validation/slopehunt_verdict.py` (outcomes A–D, self-tested).

**The ion contradiction is now cornered structurally, not just empirically.**
Resistive-sheet screening — the last candidate and the acknowledged soft spot —
was re-derived by an independent method and the retirement **hardens**: the
weighting potential factorises as Ψ_sheet(k,τ)·cont(k,z) with the continuation
factor **time-independent** (the gas is source-free and bounded by the grounded
mesh), so an in-gas source sees exactly the same temporal sheet response as an
on-sheet source. **The sheet cannot distinguish induced from deposited charge**;
the ρ_s-dependent part is 0.34 % across a factor 10 where ×4.5 was needed. ⚠️ The
two derivations agree on the verdict but **dispute the ρ-dependence** (ours flat,
the original swinging 26 %) — flagged, not resolved. Consequence: every
mechanism *inside the modelled system* is excluded, so the ×4–5 suppression must
live outside the current chain decomposition or in an assumption all the
defended pieces inherit — the **weighting-field family**, the **DAQ frame/t0
definition**, or the **mapping of the 10–90 % rise metric onto the model**.

**X/Y asymmetry: real, sim-side, and 18 %.** 0.8190 ± 0.0171 on peak Y/X
(sim ÷ data, 10.6 σ), decomposing into a charge-partition term 0.8823 ± 0.0156
(7.6 σ) and an extra-spreading term 1.0777 ± 0.0254 (3.1 σ). Charge is not lost —
both legs show Y carrying more charge at a lower peak. Excluded: the data
(symmetric once de-biased), selection (the sim is immune), and the S1
electrostatics (a strips-vs-uniform A/B moves Y/X by 0.02–0.03, the wrong way —
though the strips ARE the whole sharing anisotropy, X rms 0.46 vs Y 1.25 strips,
isotropic when uniform). It lives in Stage B/C; `kY` is probably not the culprit
since it is applied identically to both legs.

**§0a morning checklist DONE** without the desktop — the merged HV-scan product
was already on EOS. All six certifications pass on both gases, including "one
distinct field map per voltage" 8/8 and 7/7, the direct guard against the T7
voltage-label incident. At 490 V: gain 24 172 vs pooled 24 094, survival 0.9518
vs T6's independent 0.955, and f_ion **0.9006 exactly** — confirming the shipped
calib still uses the parallel-plate ψ rather than the through-mesh 0.9056 (a
known ≤0.005 understatement, not a new defect).

**det3 contaminant family prefers O₂-like attachment.** 29 of the 30 water-grid
mixtures give η = 0 *exactly*, so any finite decay excludes attachment-free
transport, and det3 decays at λ = 5.6–11.1 mm at every drift field. Agrees
independently with the freeze queue's 0.8 % H₂O + ~1 % air v_drift row. ⚠️ The
λ(E) **shape** test does not close (Magboltz rises with field, det3 falls), so
this rests on the decay existing, not on its shape — family-constraint
inference, no concentration readable.

⚠️ **`GAS_AND_DRIFT_CAGE_ROADMAP_2026-08-08.md` §2 corrected**: the wet
amp-range tables already exist (the `.gas` files store **E/p** — ×745.83 Torr
gives 5–60 kV/cm), so **zero Magboltz jobs** are needed, and the bracket as
specified would have confounded water with a Penning-model change. Wet gain
bracket submitted as condor **16705137** at rP = 0.40 across all arms, with
dry-at-auto carried separately; pre-registration in
`design/report/WET_GAIN_BRACKET_PREREG_2026-08-10.md`.

**Wet gain bracket COMPLETE (condor 16705137, 32/32, 42.4 h CPU) — 4/4
pre-registered predictions confirmed, and it makes the amplitude problem
WORSE.** Gain at 490 V: dry 45 652, +0.5 % H₂O 39 934 (×0.875, −6.1 σ), +1 %
H₂O 35 125 (**×0.769, −12.0 σ**). Survival exactly 1.0000 with zero attachment
in every arm, so the loss is **pure electron cooling** — consistent with H₂O's
12.62 eV IP sitting above both Ar metastables, quenching without opening a
Penning channel. Cross-checks: uniform-vs-meshfield ratio **1.895** against the
independently recorded 1.85, and the Penning-model delta (dry auto vs dry
rP 0.40) only ×1.0162. **Roadmap §2 step 2 decides the contaminant axis STAYS
in the gain campaign**, and the slope hunt's fixed-composition assumption needs
an error bar. ⚠️ **Consequence for the amplitude ledger:** the thread wants MORE
gain and water gives LESS — at 1 % H₂O the sim's gain would be 18 538 and the
demanded factor would rise from **×1.66 to ×2.16**. The two fitted-to-data axes
pull against each other. All water fractions remain fitted-to-data; one voltage
only, so it says nothing about the gain slope.

⚠️ **Blocked, needs Dylan:** the desktop refuses new ssh sessions pending a
**Tailscale re-authentication** (`ssh desktop true` prints the link). The T7
slope-hunt chain runs there unattended and self-merges, so it is a morning
collect either way.

### 2026-08-09 update — the W2 grid is DONE and S1's absolute amplitude is fixed; T10 still fails

**S1 is no longer blocked.** The W2 re-solve ran overnight on condor (66 family jobs + combine)
and its four products are on EOS `response_sim/s1_w2_ny512/products/` with a `README.md`
supersession note. Prompt capture 0.670026 → **0.841977 (+25.66 %)**, matching a value
**pre-registered before the products existed** from an independent full-grid CG, so the family
assembly is cross-checked at production scale by a second code path. `x_fraction_prompt` =
0.50000002 and `gd_rank` = 6200 exactly in every family (= N × [1 − 67·7/(78·8)]), which
certifies the snapped mask geometry and the pinv threshold at an N the solver battery cannot
reach. **The V6 27 %-low defect is fixed.** ⚠️ But the new grid is **ny=512**, so it re-inherits
the ~0.45 % pad-edge shoulder term audit C6 rejected for W1: three grids now exist and they are
**not interchangeable dimension-for-dimension** — read `s1_w2_ny512/README.md` before choosing one.

**T10's open question is answered, and the answer is no.** The plan said V6's re-solve might
overturn the 8.26 % slow-path failure. Like-for-like on W2 it is **7.55 % against a 2 % bar —
still FAIL** — and ρ_s alone moves the number by as much as W2 does. **§7 step 5 (LUT from
slow-path templates) remains required.**

✅ **The caching cert is fixed and W2 is certified at 1e-4** (resolved later the same morning).
The cert had been reading 1.87 % on *every* product because `test_lut_vs_solver` compared the
solver at 3101 ns against the LUT at 3000 ns — a harness misalignment, never a caching defect,
and itself a side effect of Audit A1/Fix 1 correctly raising `t_max` to 3000. Harness fixed in
`f1daf7a`; re-cert gives **worst 0.0001 PASS on both W2 rho2M and the W1 ny=1024 baseline**.
Lesson worth keeping: a correct fix in one place silently invalidated a certification in
another, and nothing re-ran it for two days.

✅ **T14 DEFAULT FROZEN by Dylan, 2026-08-09, before any comparison:
ρ_s = 2 MΩ/sq · DRY 95/5 table · det3 data bundle as-analysed.** The first
comparison runs against this default and that verdict stands. **Iteration is
pre-declared**: ρ_s and the gas/v axis are the two variables to vary afterwards,
and post-default runs are **diagnosis, not verdict**. Pre-built so later looks
need no new production: Stage B/C decoded at all four ρ_s, and a v-axis reco
variant that needs no new simulation (v enters at reconstruction). Wet gas is
the only axis needing production and is prepared-not-run. ⚠️ **There is NO
measured humidity** (Dylan, 2026-08-09): the ~1 % H₂O and the det3 drying
history were themselves inferred from v_drift by Magboltz matching, i.e. from
the same observable family T14 compares — so a contaminant hypothesis is an
**unconstrained search axis, labelled fitted-to-data**, never a physics input,
until an independent assay exists (a hygrometer on the gas line is the way
out). It does not even fit well: at the assumed ~1 % H₂O the table gives
34.81 µm/ns, **4.9 % too slow**, trading the sign of the error. The one real
constraint is on contaminant FAMILY not concentration — air/O₂ vs H₂O is
separable by attachment SHAPE (`eta_per_cm`), independently of v_drift.
Full record, including where the laundering line sits, in
`design/report/T14_FREEZE_QUEUE_2026-08-09.md`.

⚠️ *(pre-freeze analysis, kept as the evidence the decision rests on)* **TWO
DECISIONS OWED BY DYLAN BEFORE T14 — both written up side by side in
`design/report/T14_FREEZE_QUEUE_2026-08-09.md`.** The second is the **P1 water sub-item, now
quantified**: Stage B's dry table drifts at 39.14 µm/ns against the det3 bundle's measured
36.60 — **6.9 % fast**, scaling reconstructed depth by ~6.5 %. Either keep the dry table and
quote it as an input systematic, or move to a wet ~1 % H₂O table — the latter being physics
if the water fraction comes from the June bench humidity record, and laundering if it is
chosen because it closes the 6.9 %. The first is ρ_s: Re-quoting T2b's spread constraint for the production kapton+glue stack
(`d_eff` = 70.5 µm) gives **ρ_s = 1.42–2.56 MΩ/sq**, i.e. **rho2M central and rho1M below the
band**. The "1 MΩ/sq nominal" line dating from 2026-08-07 is a pre-glue artifact at bare
d_k = 75 µm. Stage B/C exists at both points so nothing is forced; see the T14 row.

Also open from the same night: `w2_production._gather()` re-reads each slab per (drive, ρ_s) —
~640 GB of repeated decompression in the X stage alone. Accepted rather than optimised overnight;
the fix belongs in the library with battery test 8 as its gate.
Detail for all of the above: `design/report/W2_NIGHT_REPORT_2026-08-09.md`.

### 2026-08-08 update (below) — S1 upgraded then superseded by V6, T6 done, T7 ran at 490 V (label accident, salvaged), overnight ladder + HV scan in flight

**S1 (kapton+glue) is DONE.** The ESL⇄pad insulator is a two-dielectric stack, not bare kapton
(`design/report/KAPTON_GLUE_2026-08-08.md`): 50 µm kapton (confirmed, header-pinned) + 18.76 µm
laminating glue over the pad, 70.5 µm series thickness, `S(0)/C(0) = 0.881583` vs the legacy
0.913043. Re-solved on condor (4 ρ_s points at the one confirmed thickness — the old {50,75,125} µm
scan axis is retired), every point certified against the closed-form sum rule to ~5e-7, and the full
test suite (`test_longitudinal/lut_vs_solver/charge_audit/induce_equivalence/daq_wft`) passes on the
new kernel. **All 12 pre-2026-08-08 S1 products are legacy bare-kapton** — `manifest --check`
excludes them from grid completeness and the glue is baked into new product filenames
(`_g19um`) so a re-solve cannot silently overwrite one. ~~Nothing further to do on S1.~~ ⚠️ **SUPERSEDED THE SAME DAY BY V6**: the dielectric stack is settled, but the pad-plane BOUNDARY is not — W1 grounds the 100 µm inter-pad channels, which are not copper, and that costs 27 % of the prompt capture (§3 V6, `design/report/V6_PAD_GAPS_2026-08-08.md`). **A W2 re-solve of the grid is now the blocker for absolute amplitude.**

**T6 (field map) is DONE.** FEM (gmsh+scikit-fem) rebuild replaced the neBEM draft, which was
disqualified by measurement (§ T6 row below). **PRODUCTION ACCEPTED same day** (git `5763342`):
1 µm map, all gates pass, 3D transparency 0.955 −0.045/+0.005. This is orthogonal to the kapton
change — the ESL is a DC equipotential in this solve, so the PCB dielectric stack does not touch
it. S2 (transparency curve `eps(E_amp/E_drift)`, funneling map, ion-endpoint classification) is
also done against the accepted map.

**T7 (S3 avalanche in the real field) — RAN 2026-08-08 16:44–18:08 at 490 V; the "voltage scan"
was an accident, salvaged as one pooled point; the real scan runs overnight.** The desktop
campaign (`run_meshfield_campaign.sh`, 56 slices) reused `mx17_aval_points.txt` from the
uniform-field era, where `--voltage` WAS the physics — against a single pre-solved 490 V
`ComponentGrid` map it measured identical 490 V physics 7 times.
**`aval_calib_meshfield_pooled.json` is the correct reduction** (all 56 slices = ONE 6400-seed
490 V point); the per-"voltage" collect output is quarantined
(`aval_calib_meshfield_QUARANTINED.json`, see `MESHFIELD_QUARANTINE_README.md`) and nothing may
read it. The physics of the pooled point is healthy and cross-checks: survival 0.9559 vs T6's
independent 3D transparency 0.955; gain 24 094 = 1.85× below the uniform-field 490 V table,
consistent with 31.0 vs 32.7 kV/cm; f_ion 0.900 vs 0.908. `mx17_aval_calib.py` (commit
`6e2aad0`) now guards `--voltage` against the map's own provenance sidecar, so the mislabel
cannot recur. ⚠ Caveat for Stage B: meshfield σ0 (94.5 µm vs uniform 33.7) and t_arrival include
the 180 µm drift leg + funnelling (seeds start above the mesh) — do not double-count drift
diffusion. Raw archived at desktop `/media/ucla/mx17_response_sim/avalanche/`
`results_meshfield_490V_20260808/`, shuttled to EOS overnight.
**OVERNIGHT (launched 18:59, `overnight_chain.sh` on the desktop, unattended):** the
gas-agnostic mesh-voltage map ladder (`voltage_ladder.sh`, 41 FEM maps 300–700 V @ 10 V,
E_drift held 333 V/cm, ~315 s each, all gates checked) → EOS shuttle → the real Ar/iso 95/5 HV
scan (`run_meshfield_hvscan.sh`, det3's bench range 460–530 V × 8 seeds = 64 slices, one ladder
map per voltage, tmax 500 ns) → merge to `aval_calib_meshfield_hvscan.json` → shuttle. Expected
complete by morning 2026-08-09 — check `/media/ucla/mx17_response_sim/overnight_chain.log`
before quoting; an audit session verified the chain mechanics (per-voltage maps genuinely
differ, sidecars travel, Kerberos through 08-09 11:21) and removed a stale process that would
have hung the wait loop. `scripts/check_ion_template_repro.py` can then run against real output
(expect `f_ion` to genuinely move vs the uniform-field calib — an all-zero template is the only
real failure it should catch).

### Where things are

| what | where |
|---|---|
| S1 kernel grid, 4 points, kapton+glue (production) | EOS `response_sim/s1_ny1024/` + `MANIFEST.csv`; 12 legacy bare-kapton points still in `s1/`, excluded from completeness |
| T6 field map (production, accepted 2026-08-08) | `~/x17/response_sim/meshfield/` + manifest |
| S3 avalanche calib (**uniform-field**, superseded once T7 lands) | EOS `response_sim/avalanche/aval_calib_v2.json`/`v3.json` (+ `raw/`, 19 GB; real v2 raw is AFS `results_v2/`, see `KAPTON_GLUE_2026-08-08.md`) |
| T7 real-field 490 V pooled point (**production**, 2026-08-08) | `response/avalanche/aval_calib_meshfield_pooled.json` (repo); raw at desktop `/media/ucla/mx17_response_sim/avalanche/results_meshfield_490V_20260808/` → EOS `avalanche/raw_meshfield_490V_20260808/`; per-"voltage" collect QUARANTINED next to it |
| T7 HV scan + gas-agnostic map ladder (**overnight 08-08→09, in flight**) | desktop `/media/ucla/mx17_response_sim/` (`meshfield_ladder/`, `avalanche/results_meshfield_hvscan/`), chain log `overnight_chain.log`; shuttles to EOS `s2/meshfield_ladder/` + `avalanche/raw_meshfield_hvscan_20260808/` |
| wet-CF₄ Magboltz | EOS `response_sim/gas/wet_cf4_drift.json` |
| DREAM noise spec | laptop `~/x17/response_sim/dream/noise_det3.json` |
| Stage B working set | desktop `~/mx17_stageb/` (kernels, clusters, calib, sim_decoded) |
| measured-data source docs | `~/PycharmProjects/nTof_x17/sps_beam_test_26/analysis/` |

### 2026-08-07 snapshot (superseded by the update above for S1/T6/T7 — kept for history)

**Nothing is running.** Desktop, lxplus and laptop are all idle; no condor jobs, no background
solves. Every product listed below is complete and on EOS.

Compute policy (§10): the **laptop is for orchestration only** — 16 GB, and another agent's jobs
share it. Real work goes to the desktop (fast, but disk is the tightest in the fleet, ~91 % full) or
lxplus/condor. Desktop reaches EOS only via `rsync … lxplus:/eos/…` with a live Kerberos ticket.

### The chain, end to end

Geant4 ClusterTree → drift/diffusion → mesh transparency (T6) → avalanche (S3) → S1 comb-kernel
induction → ion longitudinal template → DREAM shaper → FEU sampling/ADC/noise → `sim_decoded_*.root`.
**It runs, and wft's own `FeuReader` reads the output unmodified** (`run.py --decoded-out`).

### What is certified, and against what

Two columns matter as much as the numbers: whether a row is an **anchor** (checked against
something outside the code — a closed form, a datasheet, data) or an **internal-consistency**
check (the code reproducing itself, which catches regressions and nothing else). The audit of
2026-08-07 found several rows reading as anchors that are not, and they are relabelled here.

| check | result | reference | kind |
|---|---|---|---|
| S1 sum rule | 5e-7, plane partition 4e-13 | closed form S(0)/C(0) | anchor (tiling pads only) |
| real-pad capture | 0.665023 vs 0.665023, 5e-9 | (PAD_SIZE/PAD_PITCH)² × S(0)/C(0) | anchor — **asserted** since 2026-08-07 |
| V5 mesh-as-plane | 7.8e-7 vs 1 % bar | exp(−2πg/p) | **analytic bound, not a test** (see below) |
| T10 fast path, per channel | **1e-4** vs 2 % bar | `kernels.charge_budget_y/_x` | internal — two independent indexings agree |
| T10 off-grid booking (C2) | exact, 0 disagreements | LUT band's own column | internal |
| S1 time-grid adequacy | <0.5 % vs 2 % bar | 4× denser re-solve (nt 60→240) | internal |
| charge audit | **≤0.6 % at every depth** (n_side 8, t_max 3000) | `sum_over_rows`+`sum_over_columns` at the probe's own (x,y) | internal |
| ny grid convergence | **0.452 % vs a 0.3 % bar — FAILS** | ny=1024 re-solve, smeared 150 µm | internal |
| avalanche survival | P(g>0) = 1.0, 0/4080 seeds | S3 raw slices on EOS | anchor |
| ion template A/B | <1 % | analytic vs measured S3 v2 | internal |
| noise round-trip | **0.2 % / 1.5 % / 0.043** | det3 pedestals | internal |
| ADC scale end-to-end | **101.1 vs 102.4 ADC (1.2 %)** | derived 20.48 ADC/fC | anchor (datasheet-derived scale) |
| wet-CF₄, dry column | 74.66 vs 74.7 µm/ns | nTof_x17 published Magboltz | anchor — but **dry vs dry** |
| wet-CF₄ bracket | **PASS**, wet span 10.3–20.0 µm/ns | measured 13–15 µm/ns at 233 V/cm | anchor — `design/report/WET_CF4_BRACKET_2026-08-07.md` |
| V6 inter-pad gaps | **+27.2 % — FAILS the "few %" estimate** | mixed-BC solve vs W1, + independent FD | anchor — `design/report/V6_PAD_GAPS_2026-08-08.md` |
| T10 ion lateral shape | **8.26 % vs a 2 % bar — FAILS** | slow path (exact Ψ(z)) vs the fast path | internal — two paths, shared S1 product |

Notes on rows the audit corrected:
- **V5** — `v5_mesh_ripple.py` EVALUATES exp(−2πng/p) and compares it to a 1 % bar. Nothing is
  tested against anything, so this is an analytic bound, not a test. (This resolves the §0a
  "certified" vs T5 "still not run" contradiction: both were half right.)
- **charge audit** — the old "1.5 %" was measured against the grid-MEAN capture, and was an
  EXCESS, which no leak can produce. It was the reference: capture ranges 0.25–0.89 across the
  cell and a handful of probes do not average to the mean. Now evaluated per position; what
  remains is a genuine ~2 % window deficit at n_side = 4, to be re-recorded after the Fix 1
  LUT rebuild (which truncates late charge in the same direction).
- **ADC scale** — the old "98.0 vs 102.4" gap was the test injecting signal into every event and
  then taking its pedestal from those same events. With signal-free pedestal events it closes to
  1.2 %, and the tolerance is tightened from 10 % (which would have passed a +13 % gain error)
  to 3 %.
- **noise round-trip** — the 3.5 % per-channel residual was a real +3.7 % scale bug (C1),
  not estimator noise; it is 0.2 % now and the bar is 3 %.
- **per-product sum rule** — `kernels.py:492-493` re-checks only t ≤ ~0.2 ns on a reduced grid.
  The full-axis claim rests on the original T2b run, whose parameters are not recorded.
- **V1's "Riegler closed form"** shares `stack_coeffs` with the code under test. The reviewer
  re-derived C(k), S(k) by hand and they ARE correct, but the certification is narrower than
  "against an independent closed form"; an FD Laplace solve would make σ_p independent.

### ⚠️ Full-chain audit 2026-08-07 — read `design/report/AUDIT_2026-08-07.md` before T13b/T14
### → implementation spec for the fixes: `design/report/AUDIT_FIXES_2026-08-07.md`
### → what the compute-side runs actually found: `design/report/DESKTOP_RUNS_2026-08-07.md`

**Three of the audit's own conclusions did not survive being run** (details in DESKTOP_RUNS):

1. **A1's direction is wrong.** Rebuilding the LUT with a window that covers the DAQ frame
   does NOT raise the halo shares. c1_Y *falls* 11.5 % at the DAQ window (32 % over the full
   record) and c1_X does not move at all (+0.1 % over a 3× change in t_max). The corrected
   prediction sits further from the measured 0.23–0.28, not closer. Recorded as a prediction
   revision; the §9 firewall forbids tuning it back.
2. **A1's second cause does not exist.** The longitudinal convolutions were never losing
   their tail — both are already linear convolutions and padding them is bit-for-bit
   identical. The only defect was `t_max` itself.
3. **A7's avalanche-survival bias is zero, not unknown.** P(g>0) = 1.0, with 0 of 4080 seed
   electrons failing to multiply at the three lowest voltages (survival can only rise with
   field). The conditional Polya is the unconditional one and the shipped calib is unbiased.

**And one thing the fix order got exactly right, which turned out to matter most:** the
sizing trap. Opening the time window at a fixed `n_side = 4` LOSES 8–10 % of the induced
charge at every depth. **Production defaults are now `t_max_ns = 3000` AND `n_side = 8`
(`y_window_mm = 7.02`) — they are not separable**, and shipping the window fix alone would
have made the charge accounting five times worse than the bug it fixed.

⚠️ **C6 FAILS**: at the 150 µm smear floor the ny = 512 grid is off by 0.452 % against the
0.3 % bar, so production wants **ny = 1024** (~2× cost). Blocked on desktop disk, not compute.

Five adversarial reviews of the whole chain, run before any data comparison. Headlines: the
digitizer LUT truncates kernels at 1 µs (biases the d=±2/3 halo LOW — the direction of the
headline §9 tension) — rebuild before concluding anything about the halo; the §3 "in-gap"
sharing row is actually a second on-strip deposit (`nearest_column` picks by absolute x, not
ESL phase) — no genuine in-gap numbers exist in any product; the decoded output gives X and Y
independent trigger phases and writes ftst=0 (uncorrectable fake inter-plane jitter); the
"wet-CF₄" cert row is dry-vs-dry (the wet bracket check is unrecorded); attachment is absent
(blocks P1); the S3 calib drops the avalanche-survival factor (gain biased high, feeds P2);
sim FEU naming 07/08 contradicts det3's 3/4. Also resolved there: the 98.0-vs-102.4 ADC gap
(test artifact, scale correct), the phantom "avalanche size cap" (no cap exists), and P5's
inversion ambiguity (reference decoder reverses per connector, unconditionally). P6 is
resolved (below). The solver core, unit chains, Polya/diffusion statistics, and the decoded
schema were verified clean, several by hand re-derivation.

### Next, in order (updated 2026-08-08)

1. **T7 — collect the overnight HV scan (morning 2026-08-09).** The 490 V pooled point exists
   (§0a); the ladder + 460–530 V scan runs overnight unattended. Morning checklist: read
   `overnight_chain.log` (desktop) end to end — the merge and both EOS shuttles are
   warn-and-continue, so failures are silent-but-recoverable; check per-slice logs for gate/guard
   warnings; run `scripts/check_ion_template_repro.py` as a sanity display (expect `f_ion` to
   genuinely move vs the uniform-field calib, not match); then re-run the avalanche-survival and
   gain/Polya certifications that the uniform-field pass got, and re-point Stage B/C at
   `aval_calib_meshfield_hvscan.json`.
2. **T10 slow path** — Ψ at z > 0, i.e. the ion's *lateral* shape. **Machinery built 2026-08-08**
   (`response/solver/zextend.py` + `response/validation/t10_slowpath.py`). Two things to know
   before reading any T10 number:
   (a) the S1 Ψ z-slices §2 specifies **never existed** — `solve()` returns z = 0 only — but no
   re-solve is needed, because in W1 the gas gap is charge-free under a grounded mesh and
   Ψ(k,z,t) = Ψ(k,0,t)·sinh(k(g−z))/sinh(kg) exactly, whose k→0 limit IS the 1−z/g the digitizer
   already uses (FD-verified to 2nd order in `zextend`);
   (b) **the Garfield `ComponentGrid::LoadWeightingField` route of §3 point 6 was deliberately
   NOT used** — given an exact analytic lift it would add only ComponentGrid interpolation plus
   the unmerged local region-flag patch whose applicability to the weighting-field path is
   unverified. The slow path shares no code with the LUT, which is where independence matters.
   (The 2026-08-08 19:12 run was VOID — seconds-vs-ns on the S1 time axis, caught by a parallel
   audit; the k=0 self-check cannot see it because both paths read the same corrupted table.
   `to_uniform` now raises instead of extrapolating. Nothing from that run may be quoted.)
   **DONE, and it FAILS at 8.26 % against the 2 % bar** — see the T10 row and
   `design/report/T10_SLOWPATH_2026-08-08.md`. The fix (LUT from slow-path templates, §7 step 5)
   belongs after V6's W2 re-solve.
3. ~~**V6** — expose the 100 µm inter-pad gaps (W2) and re-solve; expected percent-level.~~
   **RUN 2026-08-08 and it FAILS**: +27.2 % on prompt capture, not percent-level, plus a 4.5×
   spurious sub-pad amplitude modulation that the real board does not have
   (`design/report/V6_PAD_GAPS_2026-08-08.md`). The check is done; **the W2 re-solve it implies
   is not, and that is the new blocker for any absolute amplitude.**
   **Sized 2026-08-08 evening — brute force is AFFORDABLE and is the chosen route (user):**
   ~770 core-h ±2× = one overnight condor fan-out (~128 jobs × 4 cores × 32 GB, ~1.5–2 h wall
   each), all 4 ρ_s points and all 42 kernels. The V6 report's "dense over 3120 modes per k_y"
   is structurally wrong in both directions: the gap lattice also couples ky (families of
   N≈24,960 at ny=512, 64 independent ky-classes, halved again by y-parity) — but three exact
   reductions collapse the cost: the eigendecomposition is drive-independent (one per family
   serves all 42 kernels), it serves the whole ρ_s grid (M ∝ 1/ρ_s: eigenvectors invariant,
   eigenvalues scale), and everything is real-symmetric at the production registration (8×
   faster eigh than complex). The effective-diagonal C_eff/S_eff route is NOT the production
   path: measuring its neglected off-diagonal scattering is half the brute-force operator
   anyway, and it structurally cannot fix the 4.5× sub-pad modulation (inherently
   off-diagonal). Dev cost is the real cost: 3–5 focused days; main risk = Bloch index
   bookkeeping (a bug class W1's small exact blocks never exposed). Sequencing: prototype ONE
   family block on the desktop, validated against `v6_pad_gaps.py`'s static solve at t=0 and
   the gap→0 W1 identity, then submit the 128-job grid with the `s1_ny1024` condor pattern
   (SendCredential, pinned OMP threads, new product tag — no silent overwrite). Watch the
   y-resolution of the 100 µm gap (~2 cells/gap at ny=1024 → ~few % of the 27 % effect;
   mitigate with fractional-coverage masks + a Richardson check against the static solver).
   Then re-run T10 against the W2 kernels (T10 row).
   **STARTED 2026-08-08 evening — prototype DONE, fan-out SUBMITTED (commit c425d69).**
   `response/solver/wpot_w2.py` (dynamic W2: gap free-charge constraint at all t → C_eff
   Schur complement, exact Bloch families) + `w2_validate.py` (8-test battery, ALL PASS:
   family-vs-dense 7e-12, prompt-vs-CG 3e-14, ρ_s-scaling exact 1e-12, both W1 reductions ==
   certified wpot at 7e-12, tiling sum rule 1.3e-16, production-vs-prototype 3e-8) +
   `w2_production.py` (real-arithmetic memory-ordered family jobs + combine). Two lessons the
   sizing did not predict: **(a) constraint masks must be HARD** — fractional coverage on the
   boundary support enforces the full floating-gap equation on partially-covered metal cells
   (whose only global solution is Vd = 0): capture read −14.8 % at ny=512 and 0 at ny=64
   before the snap (`mask_snap`, default on). **(b) the y-resolution systematic, measured**
   (hard-mask CG ladder vs V6 static 0.852998): ny=512 −1.29 %, ny=1024 −3.14 %, ny=2496
   −1.50 %; machinery Richardson 0.854171 = V6 +0.14 % (the full-box↔static cross-validation).
   So the ny=512 run carries a ~1–3 % grid systematic on ABSOLUTE amplitude — small against
   the 27 % it fixes; the ny=1024 W2 upgrade needs the y-parity/mirror-family reduction first
   (49,920-mode families otherwise). Submitted: 66 family jobs (64 Y-box + 2 X-box, each
   serving all 42 kernels AND all 4 ρ_s — eigenvectors are ρ_s-invariant), canaries y0/x0 =
   cluster 13353067, rest gated on their logs; slabs → EOS
   `response_sim/s1_w2_ny512/slabs/`, then `w2_production combine` (cheap, anywhere) writes
   the 4 `greens_comb_w2_*` products. Job scripts: `scripts/condor/{run_w2_family.sh,
   w2_canary.sub, w2_rest.sub}`.
   **DONE 2026-08-09.** All 66 slabs landed 04:12 (8.1 GB, 487 core-h, `wall_s`
   3376–20724 s — a 6.1× node-heterogeneity spread at identical N; `x001` alone held the
   completion gate for 2 h after 65/66 were down, so size the ny=1024 follow-up against p95,
   not the median). Combine 05:46. **Products on EOS `response_sim/s1_w2_ny512/products/`**
   (4 × 1.15 GB) with a `README.md` supersession note; combine and cert run as condor jobs
   (`run_w2_combine.sh`, `run_w2_cert.sh`) because **the laptop cannot reach /eos/experiment
   at all** — it redirects to `eosexperiment.cern.ch`, which does not resolve off-site.
   **All four ρ_s pass every pre-registered bar**: `channel_capture_prompt` = **0.841977**
   (pre-registered from an independent full-grid CG — so this is a full-scale cross-check of
   the family assembly, not a tautology), `x_fraction_prompt` = 0.50000002 (pinned at 0.5 by
   a pad-pitch translation symmetry, so the 110 vs 97.5 µm gap anisotropy cannot reach it at
   t=0), **+25.66 % vs W1** against +25.5 % predicted (V6 static +27.2 % × 0.987 ny-grid).
   `gd_rank` = 6200 in every family = N × [1 − (67·7)/(78·8)] exactly, which certifies the
   snapped mask geometry (670 × 682.5 µm) and `pinv_rtol` cutting at exactly the geometric
   rank, at a production N the battery cannot reach. Two expectations were wrong: late
   capture *rises* 0.40 % rather than staying flat, and `x_fraction_late` is also 0.5 (the
   predicted ESL-period late asymmetry does not appear, in W1 either).
   Full write-up: `design/report/W2_NIGHT_REPORT_2026-08-09.md`.
4. **T13 completion** — wft *reconstruction*, not just io, through to `events.parquet`.
5. **T13b** — τ_g closure with the unmodified `rc_line_step1/2.py`.
6. **T14** — the blind comparison, ONCE (see principle 1), **against det3 cosmic-bench data** (P1
   decision above) — not run_71/SPS. Settle the wet-Ar/iso bracket (RUN, not yet resolved — see
   P1) before running it — the effective drift gap is no longer open (30 mm, decided 2026-08-08,
   below). Needs the T7 calib in hand first.

### Open questions and problems

**P1 — DECIDED 2026-08-07 (user): simulate Ar/Iso 95/5, compare against det3 cosmic-bench data only.**

| | gas | drift field | status |
|---|---|---|---|
| **target: det3 cosmic bench** | Ar/Iso 95/5 (= Ar/iC₄H₁₀ 95/5) | 1000 V drift / 490 V mesh over 30 mm nominal = 333 V/cm | **the T14 comparison point** |
| what Stage B simulates | Ar/iC₄H₁₀ 95/5, dry | 333 V/cm (`digitize.py` `DEFAULT_DRIFT_V=1000`, `DEFAULT_MESH_V=490`, `DEFAULT_DRIFT_GAP_MM=30`) | **already matches the target — no code change needed** |
| §9 targets (run_71/SPS) | Ar/CF₄/iC₄H₁₀ 88/10/2 + 1.3–1.7 % H₂O | 233 V/cm | **SHELVED — a different detector; do not compare against it until det3 closure is done (see §9)** |

**Why this resolves it without touching the sim:** the old three-way conflict was mostly an
artifact of chasing two different data sources at once. Stage B's existing defaults are not a
guess at "some Ar/iso point" — they already *are* the det3 bench's own operating point:
333 V/cm = 1000 V / 30 mm nominal is exactly the `long_run_resist_490V_drift_1000V` sub-run in
`~/x17/cosmic_bench/det3/mx17_det3_saturday_scan_6-27-26/`, the same run T12's pedestals and noise
spec already come from. Redirecting T14's target from run_71 (SPS, CF₄-bearing, 233 V/cm) to det3
(cosmic bench, Ar/iso, 333 V/cm) removes the gas/field mismatch with zero simulation changes. The
old P1 table's "900 V" for the det3 bench was itself wrong/stale — §1 already said 1000 V; that
inconsistency is now resolved by fixing the canonical point at 1000 V drift / 490 V mesh (both a
real det3 point and the one every downstream number already uses).

This does not make P1 fully closed — it rescopes the remaining sub-items from "which of three
detectors" to "which det3 wrinkles matter":
- **Water content — RUN, not resolved.** `design/report/WET_ARISO_BRACKET_2026-08-07.md` (raw:
  `response/params/wet_ariso_drift.json`). Unlike run_71 there is no single measured band to
  bracket — det3 has two disagreeing "measured" v_drift numbers (36.6 §1, 28.1±0.7 µm/ns
  micro-TPC). At 333 V/cm / 30 mm assumed, the actual surveyed water fraction (1.46 %) gives
  v = 25.25 µm/ns — far from 36.6 (31 % off) but only ~10 % off 28.1, i.e. the measured water
  content favors the micro-TPC number over §1's, though the micro-TPC point was taken at a
  different (~19 mm) gap so this isn't conclusive. Also found: v_drift is non-monotonic in H₂O
  near this field (0.5 % *raises* it above dry before higher fractions drop it). Sharpens rather
  than closes the gap sub-item below — the two competing v_drift numbers disagree along exactly
  the axis (gap/field) that item is about.
- **Effective drift gap — DECIDED 2026-08-08 (user): 30 mm.** Use the mechanical nominal
  everywhere in this repo; this is settled and not to be re-derived or re-opened. (Earlier text
  here noted that nTof_x17 docs disagree — `mx_june_cosmic_qa/PAPER_STATUS.md` ~23 mm,
  `mx_june_wft/ANALYSIS_STATE_2026-07-31.md` 27.9±0.1(stat)±1.0(calib) mm,
  `HANDOFF_det3_vdrift_and_kernels.md` ~19 mm — that disagreement is in the *nTof_x17* measurement
  docs and is out of scope here; for this repo the number is 30 mm, full stop.) Stage B's
  `DEFAULT_DRIFT_GAP_MM=30` already matches — no code change needed, only this record.
- **HV point.** 900 V (`drift_scan_resist_490V_drift_900V`) is a real det3 point too, but it is not
  the one behind T12 or Stage B's defaults — treat it as a future scan point, not the T14 target.

Follow-on kept from before the decision, now read as "for det3" rather than "for run_71": if the
water fraction lands well above ~0, the dry Ar/iso Magboltz table Stage B currently uses inherits
the same ~3–5× v_drift error the CF₄ analysis found, and T_drift/halo-width predictions should not
be trusted until the wet bracket is run.

**P2 — simulated MIPs saturate the ADC.** 16.5 % of events peg the 12-bit ADC at 490 V. That *is* a
genuine det3 operating point (their HV scan runs 460–530 V), and per the P1 decision above 490 V
mesh / 1000 V drift is now the exact T14 target — so this is judgeable at T14 directly against
det3's own 490 V saturation rate, once the water/gap sub-items are settled.

**P3 — the ion's lateral shape is frozen at z = 0.** Ions carry 90.8 % of the induced charge and
currently get the surface kernel's lateral shape, the narrowest possible, because S1 solves only that
plane. This is T10's slow path.

**P4 — S3 runs in a uniform field.** No longer blocked on T6 (accepted 2026-08-08); the real-field
campaign (T7) is staged but not yet launched — see §0a 2026-08-08 update. Provenance is tagged
`uniform_field` on every existing calib so it cannot be mistaken for the real thing.

**P5 — FEU channel ordering — the ambiguity is RESOLVED; the relabelling is still not applied.**
det3's `run_config.json` gives `x_1..x_8 → FEU 3`, `y_1..y_8 → FEU 4`, connector-to-connector
identity within a view, but **every connector on both views is `"inverted"`**. What "inverted"
means is no longer open: `Mx17StripMap.apply_orientation` reverses within `n_channels = 64`,
i.e. **per connector, unconditionally** (audit 2026-08-07 B3). The simulation still writes the
deliberate identity mapping, which is pure relabelling and changes nothing computed so far; it
matters only for a channel-by-channel comparison at T14.

Two mechanical consequences are now handled (Fix 8): the decoded files are named by the target
run's **FEU ids** (`--feu-ids`, default `3 4` for det3 — the old hardcoded `07/08` is a
different physical detector, mx17_2, and wft keys its strip map off that suffix), and the
basename carries `_datrun_<tag>_` so that `wft/io.file_tag` can PAIR the X and Y file of a
subrun. Without the tag `reco.py`'s `by_tag` dict never assembles a pair and the run
reconstructs zero events with no error anywhere.

**The x/y sign convention is SETTLED 2026-08-08, and the simulation had it wrong.**
`ActiveAreaFrame.hh` used `sy = -1`, chosen only to keep the local frame right-handed after
the z flip. Nothing in the response chain takes a cross product, so handedness is free while a
flipped y mislabels every Y channel: `sy = +1` and the frame is now deliberately left-handed.

The convention, from the detector (user, 2026-08-08): viewed from the pixel side, X connectors
along the bottom and Y up the right, x counting left→right and y bottom→top, x FEU DREAM 1 at
the far left and y DREAM 1 at the bottom — channel 0 at the LOW end of each coordinate, which
is exactly what `mx17_m1_map.csv` encodes. So the strip map's "x0 = 0, increasing" was never an
assumption awaiting a check; it IS the wiring. The sign follows without agreeing on which way
is "up": the pads sit at larger world z than the ESL, so +z_world points toward a viewer on the
pixel side, (right, up, toward-viewer) is right-handed for any viewer, therefore
(x_det, y_det, z_local) is left-handed and sx·sy = +1.

Verified: physical bottom → row 74, top → row 444, far left → col 64, far right → col 447 on a
300 mm-spread run. The connector inversion stays on the DATA side (`apply_orientation`, already
unconditional) and the comparison happens after it. The bench is a third, swapped frame
(bench x = detector y), which is why the June M3 alignment needed ~90° plus a flip.

⚠️ Cluster files written before 2026-08-08 carry `sy = -1` in their Meta and remain
self-consistent read through it, but their y is mirrored against new files — never mix them
channel-by-channel. Every observable quoted in this plan is symmetric in y (c1/c2 average
d = ±1, the X/Y balance), so no number changes.

**P6 — DREAM undershoot — RESOLVED 2026-08-07, and the original premise was wrong.** The fix was
never the biquad: the manual (§2.1.4) sets the Sallen-Key damping to ζ = 0.75 precisely "so that the
global filter response exhibits a 1 % only undershoot" — the complex poles cannot produce −4 to −6 %.
The mechanism is the **CSA main pole**: Rf·Cf = 5 µs (state1<31> = 0 in `CosmicTb_MX17.cfg`; the
FEU 1 trigger-plane override `0x881F 0xD043` = 50 µs + 283 ns pins the register word order), which
the PZC exists to cancel (§2.1.3) and evidently does not cancel completely. `shaper.py` now
implements the manual topology (PZC real pole + ζ = 0.75 SK; reproduces the manual's 1 % as −1.12 %)
times a residual high-pass `1 − β/(1 + sτ_f)`, τ_f = 5 µs. β (the un-cancelled fraction) is not in
the datasheet → **scan/nuisance parameter like ρ_s**, default 0.75, `--pzc-residual`. Indicative:
the measured −4 to −6 % depth maps to β ≈ 0.6–0.9 and the −30 % end-of-drift-ladder lobe at 700 V
(run_71 reanalysis §3) independently to β ≈ 0.85–0.9 — two features, one parameter, consistent. At
T14 the undershoot target selects β; the ladder-lobe shape and the late-window sag are then
cross-checks, not fits. Side effects now in the model: ~1–2 % peak loss (β-dependent) and ∫h =
(1−β)·∫h_nom, so long-window area budgets are no longer shaper-invariant.

**P7 — the c1 = 0.23–0.28 target is weak.** `RAW_RUN71_REANALYSIS` §6 states c1 as a cascade-model β
"is not a robust observable in any of the passes" and directs users to the library + charge budget
instead. Weight it below the area/peak table.

**P8 — carried smaller items.** ESL registration phase unknown (assumed centred, §12 item 3); mesh
weave 5.5 % scale systematic (67 vs 63.5 µm pitch); uproot writes counter-based jagged branches
rather than true `std::vector` (invisible to wft, which is uproot-based; visible to a ROOT/C++
consumer); desktop disk ~91 % full.

### Two process rules earned the hard way

**Do not re-derive the channel indexing.** Four separate times on 2026-08-07 an ad-hoc summation over
the S1 arrays was wrong while the solver's own helpers were right — it cost most of an afternoon
chasing a 23 % "loss" that was the inter-pad copper and a 59 % "residual" that was a 20 µm source
position mismatch. The traps: y = 0 sits at `ny//2` (`_to_y0_origin`), rows alternate parity, X is
indexed by absolute column mod the 40-pad superperiod, and `check_sum_rule` deliberately substitutes
**fictitious 0.78 mm pitch-sized pads** so a closed form exists — production uses the real 0.68 mm
pads and the right reference is the product's own `channel_capture_prompt`. Always certify against
code that already passes a closed-form check.

**Check amplitude and shape separately.** A 5.7× noise scale error passed a normalised
autocorrelation check perfectly, because a pure scale error cannot move a normalised autocorrelation.

---

## 0. Goal and principles

Simulate the complete MX17 response to MIPs from first principles: Geant4 ionization → drift/diffusion → mesh transparency → avalanche gain → **charge spreading on the resistive strips + signal induction on the X/Y readout** → DREAM electronics → digitized waveforms that the existing `wft` reconstruction (in `~/PycharmProjects/nTof_x17`) can process **unchanged**.

Principles:
1. **First-principles first.** No parameter is tuned to MX17 detector data on the first pass. Measured MX17 quantities (sharing fractions, peak-time shifts, response library — §9) are *blind validation targets*. Only after the blind comparison do we iterate.

   ⚠️ **Blind means blind, and the comparison happens ONCE, at T14** (added 2026-08-07 after this was
   violated repeatedly). Do not run §9 comparisons stage by stage as the chain is built. On
   2026-08-07 the §9 numbers were consulted after almost every stage — the ρ_s scan, the ion
   template, the timing diagnostics — and it produced churn rather than progress: T10 was promoted
   to critical path and then demoted, a diffusion-vs-transport hypothesis was raised and refuted a
   run later, and a headline conclusion was published and then withdrawn. It is premature on its own
   terms as well: a mismatch cannot be attributed to anything while T10, T12 and T13 are missing or
   stubbed, so every such comparison is uninterpretable by construction. And each look erodes the
   blindness that is the only thing making the eventual comparison worth running.

   **Validate on INTERNAL physics instead**, which is what actually finds defects: charge
   conservation, sum rules, closed-form limits, impulse responses, LTI invariances, and agreement
   between two independent routes to the same quantity. Every real bug caught on 2026-08-07 came
   from one of those — the `apply_ion_transit` running mean that put 5.9 units of charge on the
   readout per unit induced was caught by an impulse test, not by any data comparison.

   **Inputs are not targets.** Which gas, which drift voltage, which mesh voltage are configuration
   that must match the apparatus; setting them from logged run conditions is not tuning. The §9
   *response* observables — sharing fractions, peak ratios, peak-time shifts, τ — are targets and
   stay untouched until T14.
2. **Staged, file-joined pipeline** (adopted from `~/CLionProjects/p2_geant/docs/SIM_CAMPAIGN_PLAN.md` §2): expensive stages run once, cheap stages re-run per parameter point. Every stage reads/writes documented files; any stage can be re-run in isolation.
3. **Two-tier fidelity.** A rigorous slow path (Garfield++ delayed-signal formalism) validates a fast path (precomputed response-function convolution). The fast path is the production digitizer. Same physics, different caching.
4. **Everything scanned that is unknown.** Resistivity, coverlay thickness, amplification gap are scan axes, not guesses.

Pipeline overview:

```
S1  Weighting solver   Ψ_n(x,y,z,t)  dynamic weighting potentials      [new python]
S2  Mesh field solver  E(x,y,z) unit cell, transparency, funneling     [Garfield++ neBEM / Elmer]
S3  Avalanche calib    gain(V), Polya θ, σ0, ion current shape         [Garfield++ microscopic]
A   Geant4             ClusterTree upgrade: time + local coords        [this repo, C++]
B   Digitizer          clusters → per-strip induced current waveforms  [new python package]
C   DREAM electronics  currents → ADC samples, noise, ZS               [new python package]
V   Validation         wft reconstruction on sim output vs data        [nTof_x17 tooling]
```

---

## 1. Detector description and parameter table

Anode stack, top (gas) to bottom. z=0 at the top surface of the ESL resistive layer, +z toward the mesh.

| # | Layer | Value | Source | Confidence |
|---|---|---|---|---|
| 1 | Micromesh (grounded ref. for amp field; at −HV_mesh in reality) | woven SS, wire 2×19 µm crossing, fill factor 0.223 | `shared/MX17ModuleGeometry.hh` | good |
| 2 | Amplification gap | **150 µm — CONFIRMED (user, 2026-08-06). Not 128. Do not scan.** | user; supersedes the "unverified" flag in `design/GEOMETRY_IMPLEMENTATION_NOTES.md` | fixed |
| 2b | Pillars (inside the amp gap) | **Dynamask** dry-film (photoimageable solder mask; user 2026-08-06), Ø 0.60 mm on a 4.68 mm grid (3571 pillars), height = gap 150 µm; area coverage ≈ 1.3% | material: user; geometry: `3498A_bulk.gbr` | good |
| 3 | **ESL resistive strips** | **550 µm wide, 250 µm gap, 800 µm pitch, running along y ("vertical")**; terminated on copper bus strips at both y-ends only (user 2026-08-07); print thickness ~10 µm (user estimate, unconfirmed — does NOT enter the model: S1 treats the ESL as a zero-thickness sheet, thickness is absorbed into ρ_s) | user/fab knowledge; NOT in gerbers (screen-printed after fab) | geometry good; ρ_s unknown → scan **{0.5, 1, 2, 5} MΩ/sq** |
| 4 | Insulator between pad Cu and ESL | **kapton 50 µm, ε_r = 3.5, CONFIRMED 2026-08-08** against `pcbKapton_um` in the header and the MX17_Full_Geant PCB stack (NOT Dynamask — that is the pillar material only; user 2026-08-06). **Plus lamination adhesive in series**: ~25 µm supplied, 18.8 µm left over the pad after squeeze-out, ε_r ≈ 3.2 → series thickness **70.5 µm** | kapton: header + CAD. glue: ESTIMATED (standard 2 mil coverlay pairing + volume bookkeeping) | kapton **fixed, no longer scanned**; glue not a production scan axis, bracket {12.5, 25, 35} µm supplied for sensitivity only |
| 5 | Pad plane (Cu) | 512×512 pads, **0.68 mm square on 0.78 mm pitch**, active area 399.36 mm | `design/gerbers/readout_pcb/DFS3498A_L2-pads.gbr` | exact |
| 6 | Buried interconnect | pads bussed by vias to 512 Y-strip traces (L3-TrackY) and 512 X-strip traces (L4-TrackX), 0.1 mm traces on 0.78 mm pitch | gerbers | exact (in-plane); layer z-spacing unknown |

Critical geometric facts:
- **Pitch mismatch / beat:** resistive pitch 800 µm vs readout pitch 780 µm. The ESL-to-pad registration phase advances 20 µm per pitch and repeats every **LCM = 31.2 mm** (39 resistive strips = 40 readout pitches). The response kernel is therefore **position-dependent with a 31.2 mm superperiod** in x. The solvers and the digitizer must carry the absolute x position, not just position-within-one-strip. This beat is itself a physics prediction to look for in data (position-dependent sharing/residuals with 31.2 mm period).
- **Orientation and sharing anisotropy:** resistive strips run along y. Resistive transport moves charge along y → spreads signal across the *y-measuring* channels → the Y view has stronger, slower sharing (data: τ_Y ≈ 410 ns vs τ_X ≈ 230 ns; kY ≈ 1.8–2.9). Across x, gaps block DC transport; X-view sharing is diffusion + induction + weak inter-strip capacitance. The simulation must reproduce this asymmetry *from geometry alone* — it is a headline validation target.
- **Strip biasing/grounding — A1 CONFIRMED as hardware, τ_g REINTERPRETED (2026-08-07):** the ESL strips contact copper bus strips at both y-ends of the active area and **nothing in between** (user, 2026-08-07 — this is now a fact, not an assumption). The implied global drain is L²/(π²D) = 4–41 ms across the ρ_s scan. The quantity previously mislabeled here as "measured global drain constant τ_g = 5.3–7.3 µs" (nTof_x17 `rc_line_step2.py`) is **not a drain measurement**: it is fitted as T_Y = T_X ⊛ [δ + d/dt(Gaussian diffusion × e^(−t/τ_g))] on a ≤1.4 µs window with the measured X template as reference, so (i) any decay common to both views — electronics, a true global drain, HV sag — cancels by construction, and (ii) an ms-scale drain is a factor 0.9998 over the window, invisible. τ_g is the *extra decay of the Y view relative to X beyond the Gaussian toy model*, i.e. a kernel-shape observable. A drain-free S1 kernel of the true comb channel, pushed through the same toy fit, reproduces an apparent τ_g ≈ 2.2–3.3 µs for on-strip deposits and ∞ for gap deposits (charge level, ρ_s 1–2 MΩ/sq; `response/validation/tau_g_reinterpretation.py`); a strip/gap mixture lands in the measured 5.3–7.3 µs band, and the mechanism is position-flat along the strip and fleet-consistent, both as observed. Consequence for the solver: **`tau_drain_s=None` is the production default** (§3). The digitizer-level closure (run the actual rc_line fit on simulated waveforms) is task T13b.
- Gas: Ar/iso 95/5 (+~1% H2O on the bench — matters, measured v_drift 36.6 µm/ns is far below dry Magboltz). Drift gap 30 mm nominal at 1000 V / 490 V mesh — this is the det3 `long_run_resist_490V_drift_1000V` run, and per the **P1 decision (§0a)** it is now the sole T14 target; do not compare against run_71/SPS. Water fraction and effective gap for this exact run are still open — see §0a P1 sub-items.

---

## 2. Repository layout and file contracts

New code lives in this repo under `response/` (Python ≥3.10, numpy/scipy only for the core; ROOT via `uproot` for I/O):

```
response/
  solver/          S1 semi-spectral weighting solver
  meshcell/        S2 unit-cell scripts (Garfield++/neBEM driver + collectors)
  avalanche/       S3 calibration campaign scripts + frozen JSON outputs
  digitizer/       B  cluster → strip-current pipeline
  dream/           C  electronics + ZS emulation
  validation/      V  closure scripts, blind-comparison figures
  common/          geometry constants (single source: parse shared/MX17ModuleGeometry.hh
                   values into python once, assert against the header at import)
  params/          *.yaml parameter sets (one file per scan point; git-tracked)
```

Large products (grids, libraries, waveform files) never go in git. **Canonical bulk store is EOS: `/eos/experiment/ntof/data/x17/response_sim/`** (user, 2026-08-07 — effectively unlimited under the nTOF allocation), laid out as `s1/ s2/ avalanche/raw/ clusters/ currents/`. `~/x17/response_sim/` on the laptop is a *working copy*, not the archive, and the desktop holds nothing permanently (20 GB free there is the tightest disk in the fleet).

Transfer routing. **All three hosts can write EOS** (desktop enabled 2026-08-07). Two details that are not obvious and will waste an afternoon if forgotten:

- There is **no `/eos` mount and no `eos`/`xrdcp` client on the desktop.** Its access is via `ssh lxplus` with GSSAPI credential delegation — `~/.ssh/config` there already sets `GSSAPIAuthentication`/`GSSAPIDelegateCredentials yes`, so a plain `rsync … lxplus:/eos/…` works. There is no local `/eos/...` path to write to, so any script that assumes one fails with "No such file or directory".
- That route depends on a **Kerberos ticket, which expires** (24 h; `klist` on the desktop to check). Before the ticket existed, desktop→lxplus could read EOS but writes failed with "Operation not permitted" and even `.bashrc` was unreadable — so a *silent* AFS/EOS permission failure in an unattended desktop job means the ticket lapsed, not that the code is wrong. Long campaigns should either renew it or fall back to desktop → laptop → EOS.

Anything produced on the desktop must be drained on a `.done` marker written *after* the producer returns, never on file existence: rsync of a file numpy is still writing produces a silently truncated archive (cost us one bad 1 GB transfer). Every product file embeds: git hash of `response/`, the parameter YAML content, and a UTC timestamp. **No un-manifested runs** — one CSV manifest row per production run (copy the discipline from p2 `SIM_CAMPAIGN_PLAN.md` §"bookkeeping").

Key file contracts (formats frozen here; extend, don't break):

| Product | Producer | Format |
|---|---|---|
| `wpot_<ch>_<params>.npz` | S1 | Ψ_n on grid: axes `x` (over 31.2 mm superperiod, ≤10 µm step near strip edges), `y` (relative, to ±25 mm), `z` {0, 8–16 slices to mesh}, `t` (60 log-spaced, 0.1 ns–10 µs); arrays `psi[t,z,y,x]`, prompt slice `psi_p[z,y,x]` |
| `greens_<params>.npz` | S1 post | G_n(x0,y0,t): induced charge on channel n (X and Y sets) for unit point charge landing at (x0,y0); same axes; this is Ψ on the z=0 plane by reciprocity |
| `meshfield.root/.txt` | S2 | E-field map of one weave unit cell, amp gap + last 200 µm of drift |
| `aval_calib.json` | S3 | per (gas, HV, gap): mean gain ḡ, Polya θ, transverse avalanche σ0, funneling offset map, ion current shape i_ion(t) (normalized), ion fraction to mesh, transparency ε(E_d/E_a) |
| `clusters.root` | A | ClusterTree (schema §6) |
| `currents_<ev>.npz` / batched | B | per-event dict: `{channel_id: i(t)}` on a 1 ns grid, plus truth block |
| `sim_decoded.root` | C | **identical schema to data** `decoded_root/*_<feu>.root` tree `nt` (`eventId`, `amplitude[n_samp×512]`, `ftst`) so `wft/io.py` reads it unchanged |

---
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

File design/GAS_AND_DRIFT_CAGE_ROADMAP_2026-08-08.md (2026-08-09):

# Gas campaign + drift-cage simulation roadmap — recorded 2026-08-08

**What this is:** future-work spec recorded from a discussion with Dylan on the evening of
2026-08-08, immediately after the T7 voltage-label incident (see `RESPONSE_SIM_PLAN.md` §0a and
the guard in `response/avalanche/mx17_aval_calib.py`). Nothing here is launched. Fold into
`RESPONSE_SIM_PLAN.md` on its next touch — it was being edited by another session when this was
written, so this lives standalone to avoid a collision.

**Context you need first:** the T6 field map is pure electrostatics — **gas never enters the
FEM solve**, so one map per (V_mesh, E_drift) serves every gas below. The overnight 2026-08-08
job (other session) is solving the gas-agnostic mesh-voltage ladder (~300–700 V) onto the
desktop's `/media/ucla` disk; the per-gas Garfield avalanche campaigns below run *later*
against that ladder.

---

## 1. Target gases — at least these four

| # | Mixture | Where used | Amp-range `.gas` table (nTof_x17 `garfield_sim/gas_tables/`) |
|---|---|---|---|
| 1 | Ar/iC₄H₁₀ 95/5 | cosmic bench (June) | `Ar_iC4H10_95_5_Saclay_160m.gas` ✅ exists (dry) |
| 2 | Ar/iC₄H₁₀ 90/10 | nTOF (July beam) | `Ar_iC4H10_90_10_Saclay_160m.gas` ✅ exists |
| 3 | Ar/CO₂/iC₄H₁₀ 95/3/2 | SPS — **⚠ ratios to double-check before running** | ❌ no table — needs a Magboltz job (nTof_x17 `garfield_sim` EOS/condor workflow) |
| 4 | Ar/CF₄/iC₄H₁₀ 88/10/2 | SPS | `Ar_CF4_iC4H10_88_10_2_Saclay_160m.gas` ✅ exists |

Practicalities, all four being Ar-dominant:

- **Ion mobility:** `mx17_aval_calib.py` hardcodes `IonMobility_Ar+_Ar.txt` — correct for all
  four. (It is wrong for Ne/He/CF4-dominant gases; irrelevant here but the reason the gas list
  can't be extended blindly.)
- **Penning:** `--penning auto` works for the common Ar binaries; for the two *ternary*
  mixtures Garfield's built-in table may not exist, in which case the script deliberately exits
  rather than run at rP = 0. If that happens, rerun `--penning manual --penning-rp <value>` and
  record the choice (the uniform-field campaign used auto on 95/5 only, so this is untested).
- **Voltage ranges:** per-gas, centred on each gas's actual operating point from the bench/beam
  records — this is what sized the overnight map ladder's min→max span.

## 2. Contaminants (H₂O etc.) — open question, with a proposed cheap answer

The drift-velocity work hypothesises **site-dependent water contamination** (cosmic bench ~1 %
and drying over a week — `micro-tpc` June work; nTOF ~0.2 % trace — July 90/10 study). Taken
literally that multiplies every gas above by a contamination axis, which is a lot of Magboltz
jobs and campaign slices.

**Unknown:** how much water matters for *gain* (amplification, 30–45 kV/cm) as opposed to
*drift velocity* (200–330 V/cm), where its effect is established and large. These are very
different reduced-field regimes; the drift-side sensitivity does not automatically carry over.

**Proposed strategy (not yet approved as a decision, recorded as the leading idea):**

1. Do a **sensitivity bracket first**, not the full grid: dry vs +0.5 % vs +1 % H₂O for ONE gas
   (Ar/iso 95/5) at ONE voltage (490 V), ~8 slices each. Needs wet *amp-range* Magboltz tables
   — the existing wet suites (`wet_ariso_bracket`, `wet_cf4_drift`) are drift-range only, so
   this is ~2 new Magboltz jobs before any Garfield.
2. Compare the gain shift against the calibration floor (geometry dominates the gain error
   budget; Penning is ±1–8 V equivalent — see nTof_x17 `garfield_sim` error-budget notes). If
   water moves gain by less than a few %, **drop the contaminant axis from the gain campaign
   entirely** and keep contaminants only where they are known to matter (drift transport).
3. Only if the bracket shows a real effect does the per-site contamination grid get built.

Note the field-map ladder is unaffected either way — contaminants, like gases, never enter the
FEM solve.

## 3. Drift-cage / degrador simulation — geometry recorded, study not started

A **separate, macroscopic** FEM problem, not the 67 µm mesh unit cell: the full 30 mm drift
volume with the mesh plane as a flat equipotential boundary. Same gmsh + scikit-fem toolchain
as `solve_fieldmap.py`. The two solves couple only through the electron-transparency ratio
eps(E_amp/E_drift), already measured (S2, `response/meshcell/transparency_curve.csv`).

**Geometry (Dylan, 2026-08-08 — verbal, verify against drawings before meshing):**

- 3 copper rings on a degrador PCB at the drift-gap perimeter, **evenly spaced along the 30 mm
  gap**.
- Ring widths such that the exposed copper and the PCB gaps between rings are of **roughly
  equal extent**, with **PCB (not copper) at the top and bottom** of the stack.
- Electrical: **top ring tied to the full drift voltage**, then ~1 GΩ top→middle, ~1 GΩ
  middle→bottom, ~1 GΩ bottom→ground. Equal steps ⇒ nominal ring potentials V, ⅔V, ⅓V.
- The ~1 GΩ is nominal. **Verification task (later):** fit the effective chain resistance from
  drift-HV current vs voltage readings at all three sites — nTOF, cosmic bench, SPS. One data
  point already exists: run_79 non-B drift channels drew ~0.18 µA at ~700 V ⇒ R ≈ 3.9 GΩ total,
  ~1.3 GΩ/ring (nTof_x17 memory `drift-cage-degrador-rings`).

**Planned study (when picked up):**

- Solve the cage **with and without the ring divider** (floating/removed rings ≠ graded
  solution — a floating conductor distorts the boundary field). Detector B ran the whole nTOF
  campaign with its degrador physically removed and shows a real, unexplained slowdown
  (nTof_x17 memory `detector-b-anomaly`) — this solve is the direct test of that mechanism.
- Sweep drift field. Gain is insensitive to E_drift (mesh penetration ~2 V at 490 V), so
  drift-field variations live in this solve + transparency interpolation, not in new avalanche
  campaigns; only add E_drift as a second *mesh-map* axis if transparency fidelity beyond the
  S2 curve is needed.
- Deliverables: field-uniformity map of the drift volume, edge-distortion extent with/without
  rings, and a predicted drift-time/velocity signature to compare against detector B.

**Do not start the cage solve before confirming the ring geometry against drawings/photos and
getting the chamber-wall boundary condition from Dylan.**

---

## ⚠️ CORRECTION 2026-08-10 — §2 step 1 needs no Magboltz jobs, and its
## comparison had a Penning confound

Found while actually setting the bracket up (`WET_GAIN_BRACKET_PREREG_2026-08-10.md`,
submitted as condor cluster 16705137).

**1. "~2 new Magboltz jobs before any Garfield" is wrong — zero are needed.**
§2 step 1 says the existing wet suites are drift-range only. They are not. All
three mixtures already exist at *amplification* range, on an identical grid, at
the bench pressure:

| table (`Saclay_160m`, 745.83 Torr) | E grid |
|---|---|
| `Ar_iC4H10_95_5` | 5 000 – 60 002 V/cm, 20 log points |
| `Ar_iC4H10_H2O_94p5_5_0p5` | identical |
| `Ar_iC4H10_H2O_94_5_1` | identical |

The trap is a units one and is worth carrying forward: **`.gas` files store
E/p**, so the header's `E fields  6.704 … 80.45` is in V/(cm·Torr) and reads as
a drift-range table until it is multiplied by 745.83 Torr. Tables that really
are drift-range carry an explicit `_drift_` in the filename
(`Ar_iC4H10_95_5_drift_Saclay_160m.gas`). The §1 table's claim that the 95/5
amp-range table "exists (dry)" was right; the §2 claim that the *wet* ones do
not was the units trap.

**2. The bracket as specified would have confounded water with Penning.**
`mm_config.py` gives dry `penning: auto` but both wet mixtures `penning: manual,
rP = 0.4` — unavoidably, since Garfield has no ternary Ar/iC₄H₁₀/H₂O Penning
table (exactly the failure mode §1 already warns about for the ternaries).
Running dry-as-configured against wet-as-configured therefore measures water
*plus* a change of Penning model, and Penning is the one knob the T7 slope hunt
is currently varying.

Penning is applied at avalanche time (`mm_sim_core.py:69-73`,
`EnablePenningTransfer` after `LoadGasFile`) and is **not** baked into the
`.gas` file, so the tables are Penning-agnostic and the setting is a runtime
choice. **The wet-vs-dry comparison is only interpretable within the rP = 0.40
arms**; a fourth dry-at-auto arm is carried solely to measure the Penning-model
delta itself, and must never be differenced against a wet arm.

**3. Labelling, unchanged.** Every water fraction here remains
**fitted-to-data** — there is no hygrometer reading behind any of it. The
bracket measures a *derivative* (would water, if present, move gain?), which
does not require the operating point to be established, and it cannot be quoted
as evidence that the bench gas contained water.

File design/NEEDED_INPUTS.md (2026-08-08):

# Needed external inputs — the register of what the MX17 model assumes

**Written:** 2026-08-06, when the as-built geometry
(`shared/MX17ModuleGeometry.hh`) landed. One place for every number the module
description *assumes* because nobody has given us the measurement, ordered by
how much the answer would move a result. Each item states the current
assumption, why it matters, and what to ask for. Companion figure:
`design/figures/mx17_stack_status.png`.

Legend: ⬜ needed · 🟡 partially known · ✅ resolved.

---

## 1. ⬜ Micromesh weave specification

**Assume now:** the P2 weave — 19 µm wire, 48 µm opening → 38 µm
effective-density slab at fill 0.223 (areal mass of a plain weave). Chosen as
a placeholder on 2026-08-06 because the real MX17 spec was not to hand.

**Why it matters:** the mesh is directly above the amplification gap; its
areal mass sets electron backscatter/absorption at the gap boundary and the
X-ray conversion rate closest to the amp region. The previous solid-30 µm
model overstated the mass ×3.5; a wrong weave spec moves it by tens of
percent. Optical transparency (~51 % for the P2 weave) is *not* modelled —
only the material budget.

**Ask for:** the mesh designation on the MX17 build sheet (e.g. "48/19" or
wires-per-inch + wire Ø).

## 2. ⬜ Operating gas overpressure (window bulge)

**Assume now:** ~3 mbar → 8 mm sag from Hencky's membrane solution
(w₀ ≈ 0.662·a·(p·a/(E·t))^⅓, a = 200.1 mm half-span, E = 4.5 GPa, t = 60 µm).
Exposed as `--bulge-front <mm>`; the p^⅓ scaling means 1–10 mbar only spans
≈ 6–12 mm.

**Why it matters:** the bulge adds up to 8 mm of chamber gas on the beam path
ahead of the drift region and changes the window-to-mesh distance across the
face. A pressure reading, or an actual sag measurement with a ruler, pins it.

## 3. ⬜ Rohacell-back aluminized mylar thicknesses

**Assume now:** 25 µm mylar + 0.1 µm Al (Al side unknown; modelled facing
downstream), 470 mm face, replacing the old 50 µm bare-Al guess.

**Why it matters:** small on-axis effect (it sits behind the 1.70 mm board and
5 mm rohacell), but it is the last layer before the support plate and shows up
in albedo/backscatter for the Sr-90 runs. A caliper or datasheet number ends
the guess.

## 4. ✅ Amplification gap: 150 µm

**Confirmed by Dylan, 2026-08-06.** The 150 µm both sims carried is correct;
the 128 µm bulk-standard question is closed.

## 5. 🟡 Which side the window Al and cathode Cu face

**Assume now:** both metals face the drift gas (mylar → Al and kapton → Cu in
beam order). This is the physically sensible reading — P2 confirmed the
analogous question for their cathode ("Al on gas side") — but it is untraced
for MX17.

**Why it matters:** sub-µm layers; irrelevant to energy deposit, marginally
relevant to very-low-energy electron emission off the surfaces.

## 6. 🟡 Readout PCB internal stackup

> **Partially closed for the RESPONSE side 2026-08-08 (V6,
> `design/report/V6_PAD_GAPS_2026-08-08.md`):** the internal dielectric split
> does not propagate into the induced signal — bracketing the board under the
> inter-pad gaps from "ground at the pad plane" to "no conductor at all" moves
> prompt capture by only 1.7 %, so the ±90 µm FR4 ambiguity below is irrelevant
> to the weighting solve. The fab stackup drawing is still wanted for the
> GEANT4/material-budget side (backscatter off the board) and to settle the
> header's kapton→L3→FR4→pads ordering question — but it is no longer a
> response-chain blocker.

**Now measured (2026-08-06, rev 2).** The copper is modelled as the five
physical gerber layers (L3 guard ring, L4 pads, L5 Y strips, L6 X strips,
L7 fan-out; L8 carries only the outline stroke), each a 26 µm sheet
density-scaled by its measured area coverage, and each split into two zones —
inside and outside the 399.36 mm active window:

| layer | active | outside | board avg |
|---|---|---|---|
| L3 guard  | 0.0000 | 0.3385 | 0.0941 |
| L4 pads | 0.7600 | 0.0568 | 0.5645 |
| L5 Y | 0.4577 | 0.1189 | 0.3635 |
| L6 X | 0.4568 | 0.1194 | 0.3630 |
| L7 fan-out| 0.5285 | 0.0584 | 0.3978 |

**How the FR4 filler is obtained (and the assumption buried in it).** The CAD
gives one number for the readout board: a 1.70 mm solid body, mesh front face
to laminate back face. The model does not know the real internal dielectric
split, so it treats the FR4 as the *residual*: it subtracts everything whose
thickness we do think we know — mesh, amp gap, ESL, kapton, and the five 26 µm
copper layers — and divides what is left equally over the five FR4 layers.

The consequence is that **changing any other layer silently changes the FR4**.
When the ESL went 100 → 10 µm, the residual grew by 90 µm and the FR4 filler
went 246.4 → 264.4 µm per layer, keeping the board at exactly 1.7000 mm.

That is a *choice*, and it may be the wrong one. It assumes the CAD 1.70 mm is
the reliable number and the laminate takes up the slack. The alternative — that
the dielectric stack is fixed and the real board is 1.61 mm — is equally
consistent with what we know. The two differ by 90 µm of FR4, which is not
nothing for backscatter off the board.

**Needed:** a fab stackup drawing, which would settle the per-layer dielectric
thicknesses and turn this residual into a real number. Until then, anyone
reading a board-body thickness out of this model should know it is pinned to
CAD by construction, not derived.

Two corrections went in with this revision, both of which changed the as-built
result (`--legacy-geometry` is unaffected and remains bit-identical):

1. **Rasterizer bias.** `analyze_cu_coverage.py` drew every aperture with
   PIL's endpoint-*inclusive* `rectangle`/`ellipse`, inflating each feature by
   one pixel per dimension — +16 % on the 0.68 mm pads at the old 0.05 mm/px
   default. The previous numbers (0.095/0.651/0.419/0.420/0.456) were
   therefore ~13 % high on every fine-featured layer; the L3 guard ring, being
   one large solid shape, was almost unaffected. Fixed, default raster raised
   to 0.02 mm/px, and `--selftest` now checks the rasterizer against the
   analytically exact pad grid (0.68²/0.78² = 0.76003) so it cannot regress.
2. **Radial smearing.** One board-wide coverage per layer put ~26 % too little
   copper in the active area and up to 10× too much outside it. Hence the
   two-zone build, which costs nothing.

**Still open:** the per-layer copper *thickness* (26 µm is the historical
guess; ½-oz 18 µm is the common fab default) and the kapton/dielectric split.
A fab stackup drawing would settle it — this is now the dominant uncertainty
on the board, well above the ~0.2 % residuals in the coverage measurement.

**Update 2026-08-08 — the coverlay kapton is closed, the adhesive under it is
not.** The kapton is 50 µm (`pcbKapton_um`, matching the MX17_Full_Geant PCB
stack), so it is no longer a response-model scan axis. What is *not* known is
the acrylic adhesive laminating it to the pad copper. Estimated at 25 µm as
supplied — the standard pairing for a 2 mil coverlay — less the volume that
lamination drives into the 100 µm trenches between the 26 µm-tall pads, giving
**18.8 µm over the pad face**. That is 29 % of the insulator the pads see and
moves the prompt sum rule S(0)/C(0) from 0.913043 to 0.881583, so it is not a
rounding error. Two things would close it: the same fab stackup drawing, or a
direct capacitance measurement of a pad against the ESL.

**🟡 Sub-question, and it is the one that actually decides the number: does a
coverlay adhesive spec quote the AS-SUPPLIED coating or the FINAL BOND LINE
over copper?** This is a datasheet/process fact, not physics, and it is open
(2026-08-08). It selects `GLUE_FLOW_MODEL` in `response/common/constants.py`:

- *as-supplied* → `"conserved"` (the default). Lamination redistributes the
  adhesive; the channels between pads must fill from somewhere and the only
  source is the adhesive itself, so the over-pad layer thins by the channel
  volume. Adhesive **flow is a specified, required property** of coverlay —
  void-free encapsulation of copper topography is the whole point, "low-flow"
  coverlay is sold separately *because* flow is the default, and a heated
  vacuum press exists precisely to fill the channels rather than trap air. On a
  400 mm panel the interior is a closed system: ~200 mm of viscous thermoset to
  a free edge. The 50 µm film cannot dip into a 100 µm channel either
  (span/thickness = 2, so it is rigid there and sits flat on the pad tops).
- *final bond line* → `"uniform"`. The spec already accounts for flow, so no
  correction applies.

**It matters less than it looks.** `conserved` at 25 µm supplied gives
d_eff = 70.5 µm; `uniform` at 18 µm gives 69.7 µm — the two disagreements
largely cancel. Across the whole plausible space (either model, 12–35 µm
supplied) d_eff spans 56–88 µm, *all* of it far from the 50 µm that assuming no
glue would give. Production stays `conserved` @ 25 µm (decision 2026-08-08).
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

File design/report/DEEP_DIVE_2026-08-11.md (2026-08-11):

# Deep dive 2026-08-11 — two defects found, the SPS data interrogated, and the campaign parked for MPGD26

**The question asked** (Dylan, morning of 2026-08-11): one more attempt to
resolve the T14 rise-time and amplitude discrepancies before deciding whether
to push before the MPGD26 talk (Prague, 3 September) or defer; and whether the
"much more precise" det4 SPS data could help.
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

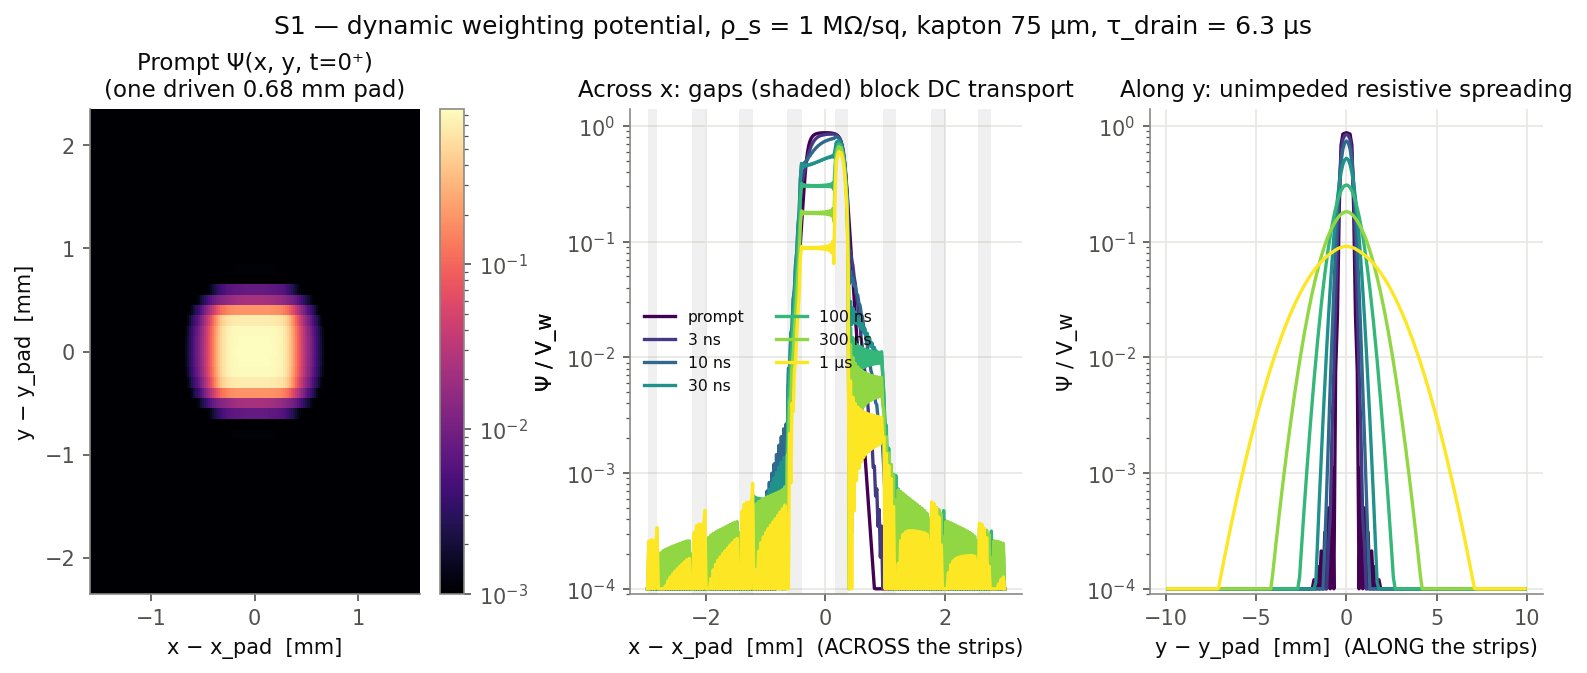
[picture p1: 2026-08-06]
design/figures/response/s1_psi_evolution.png

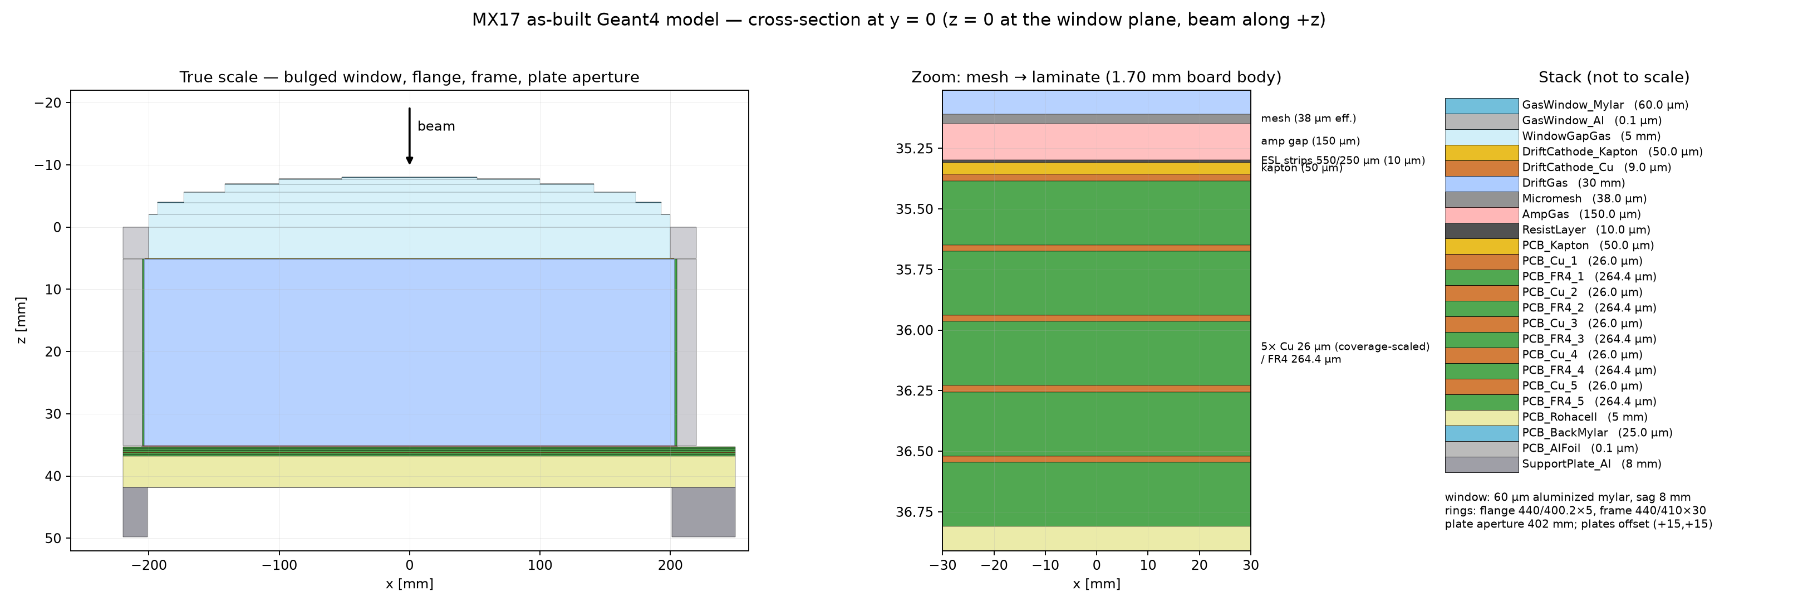
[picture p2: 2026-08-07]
design/figures/mx17_stack_xsec.png

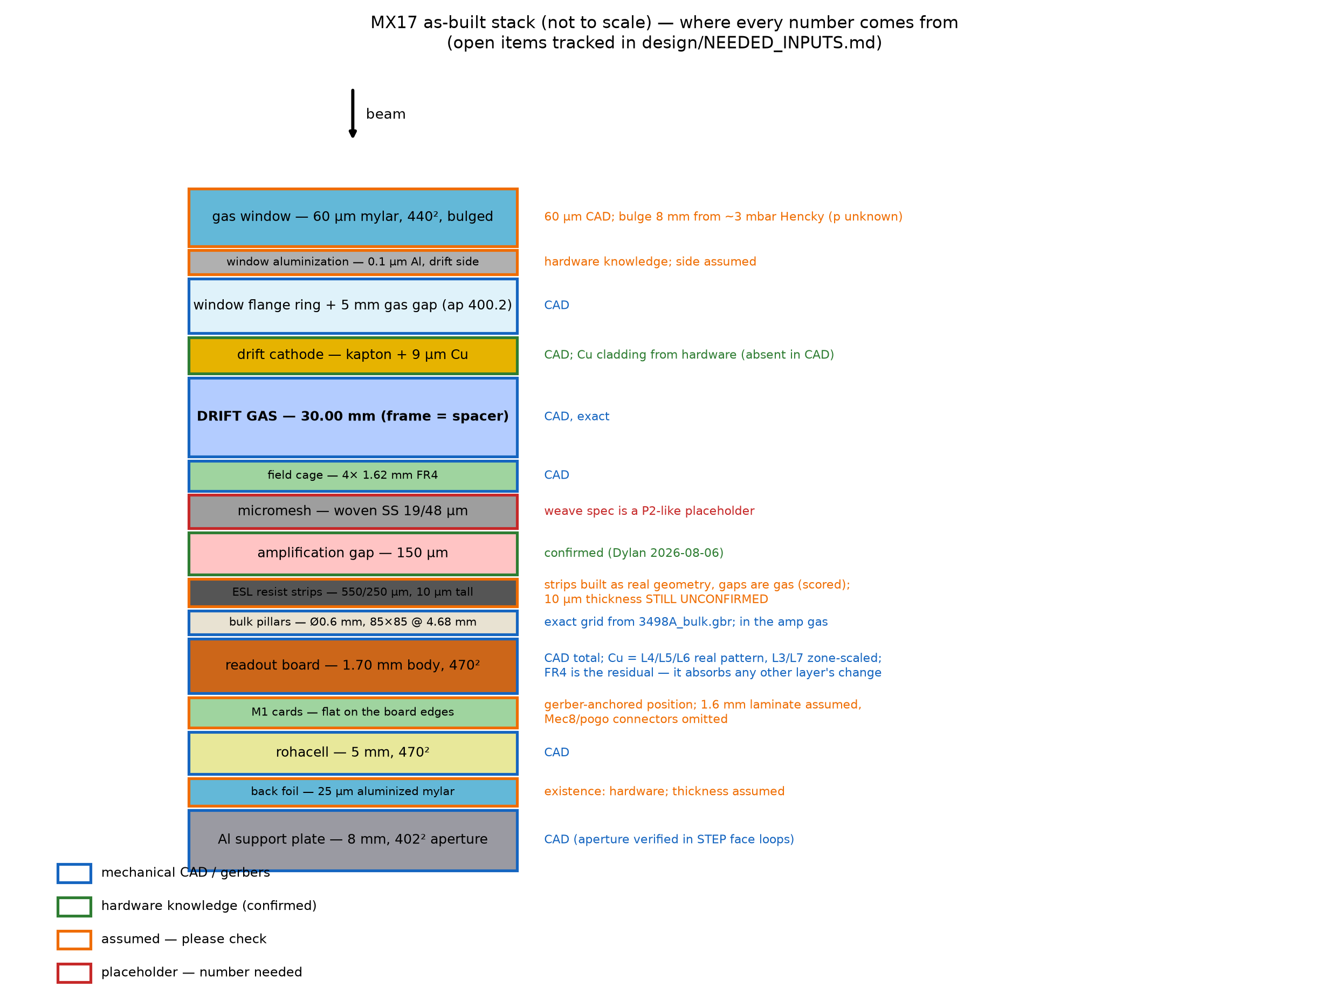
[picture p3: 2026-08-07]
design/figures/mx17_stack_status.png

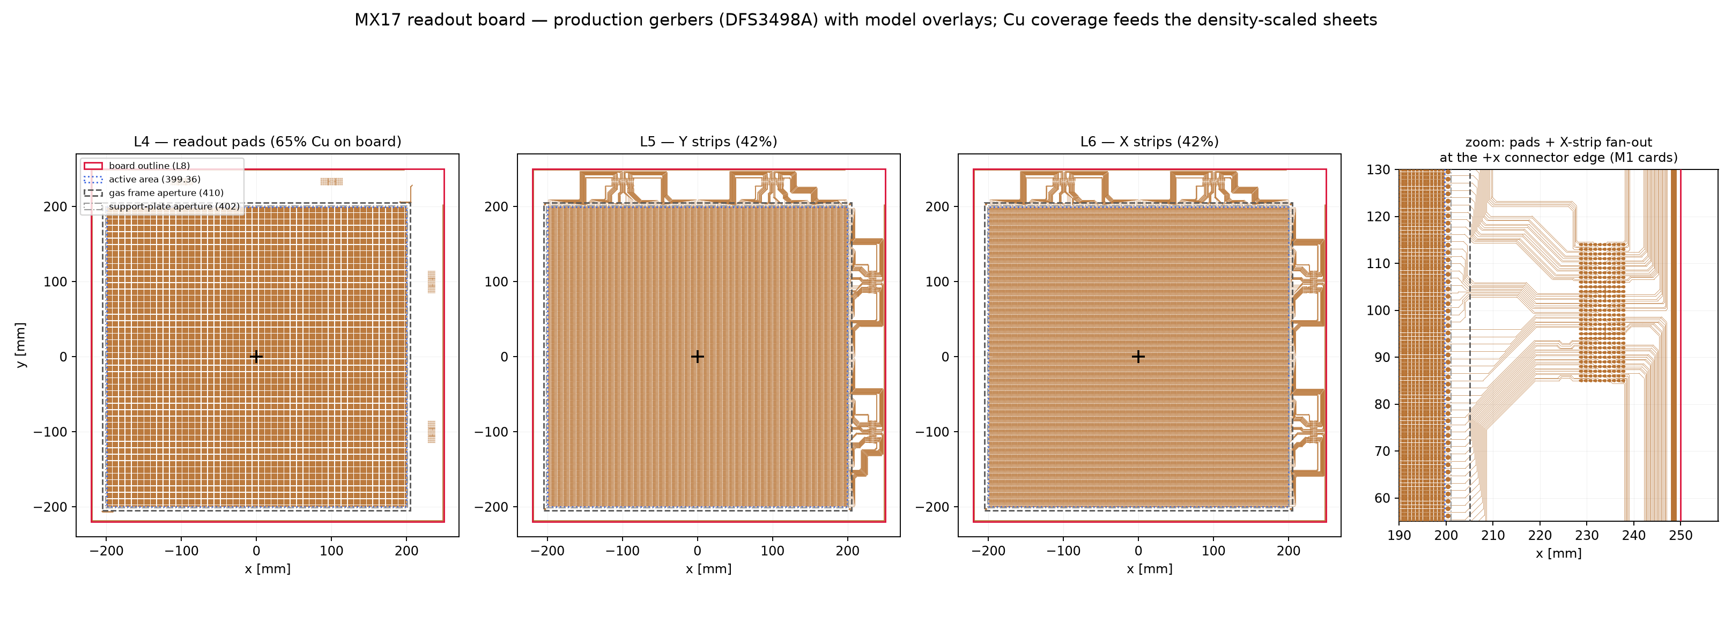
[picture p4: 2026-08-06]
design/figures/mx17_board_copper.png

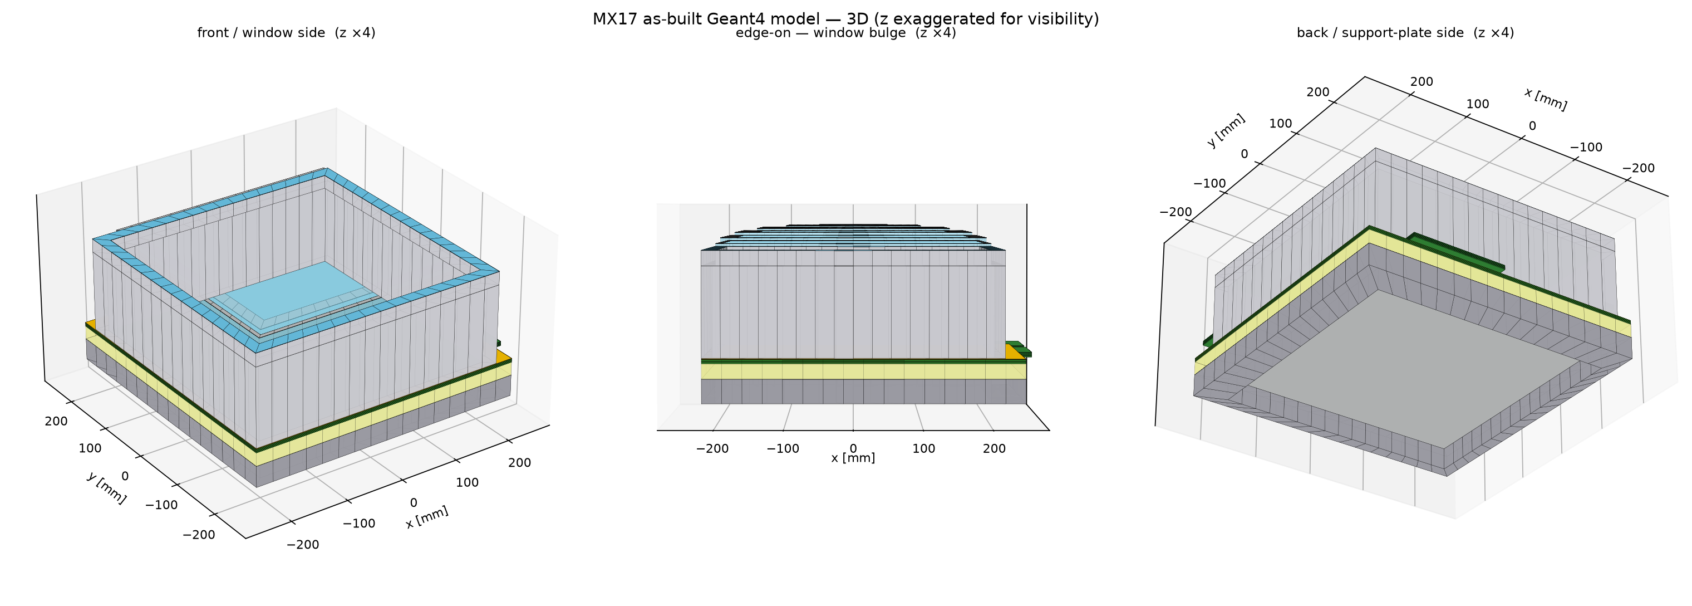
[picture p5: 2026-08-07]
design/figures/mx17_3d_overview.png

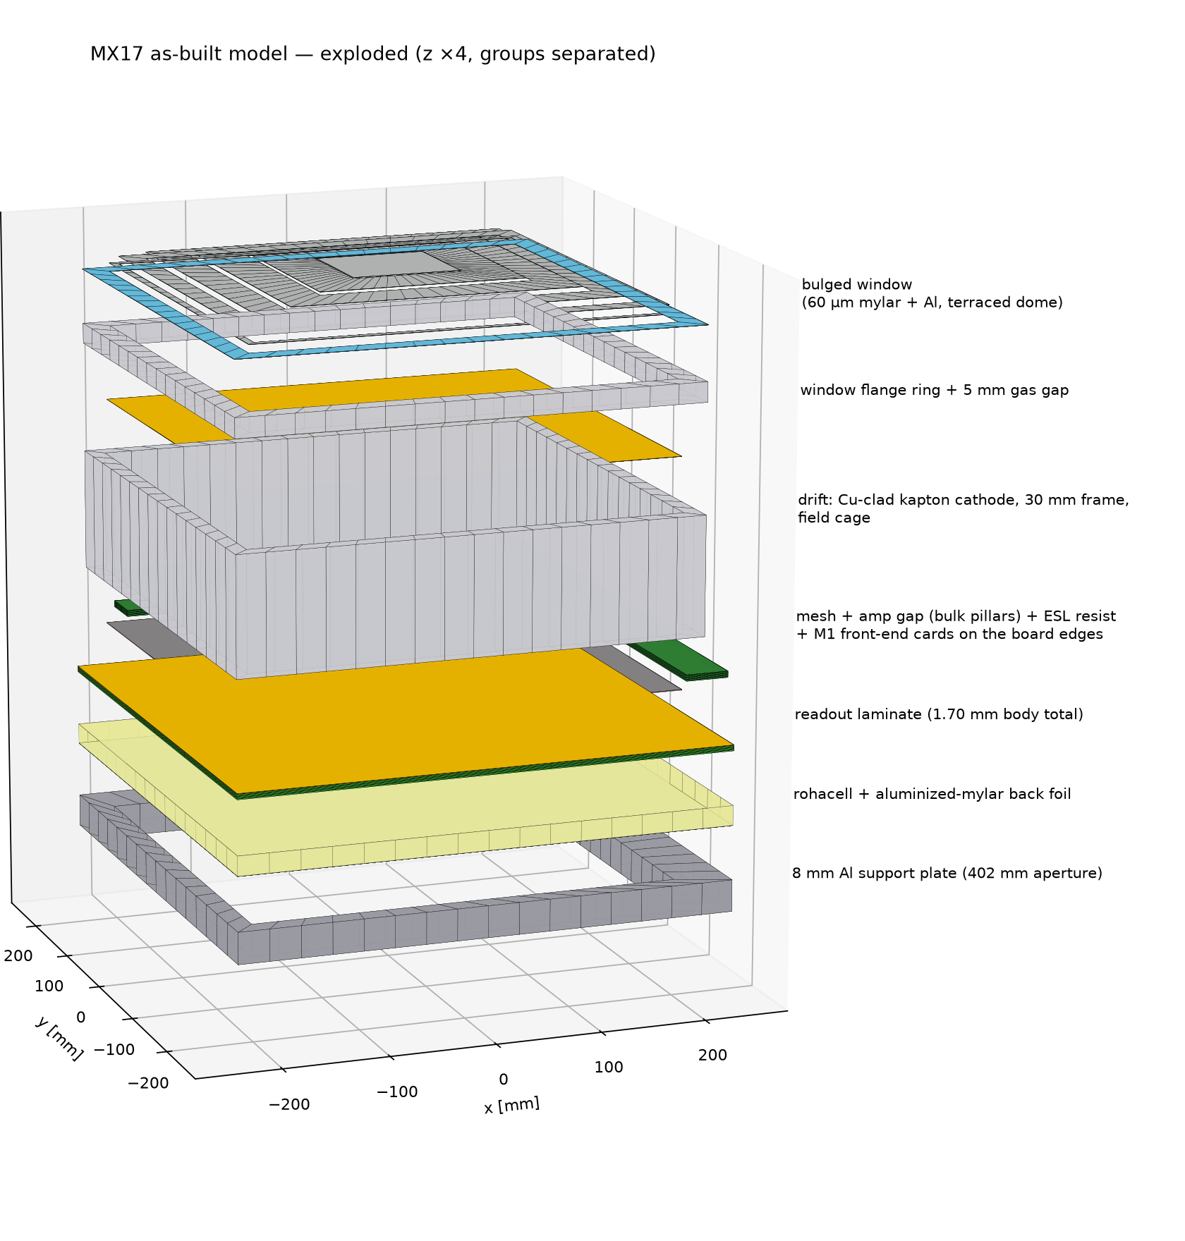
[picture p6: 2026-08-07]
design/figures/mx17_3d_exploded.png

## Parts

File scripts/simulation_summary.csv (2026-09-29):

file_source | particle | avg_edep | weighted_span | point_fraction | total_tracks
ArCO2_neutron_1p07MeV_t0.root | Ar36 | 107576.42993555171 | 0.08158142391125761 | 1.0 | 2.0
ArCO2_neutron_1p07MeV_t0.root | Ar40 | 101676.53733671906 | 0.08147193700164097 | 1.0 | 77.0
ArCO2_neutron_1p07MeV_t0.root | C12 | 199654.22339531264 | 0.6640885044956405 | 1.0 | 364.0
ArCO2_neutron_1p07MeV_t0.root | C13 | 228202.38107298757 | 0.6538352106168039 | 1.0 | 3.0
ArCO2_neutron_1p07MeV_t0.root | O16 | 200247.18500701265 | 0.5222160056515365 | 1.0 | 1066.0
ArCO2_neutron_1p07MeV_t0.root | O18 | 137772.8570831405 | 0.40032758513616334 | 1.0 | 2.0
ArCO2_neutron_1p07MeV_t0.root | e+ | 38.841554240357 | 0.0 | 1.0 | 1.0
ArCO2_neutron_1p07MeV_t0.root | e- | 4885.688771432166 | 53.40264653222082 | 0.8235294117647058 | 68.0
ArCO2_neutron_1p07MeV_t0.root | gamma | 69.07444444444452 | 0.0 | 1.0 | 9.0
ArCO2_neutron_1p07MeV_t0.root | neutron | 38503.32412383556 | 0.0 | 1.0 | 2336.0
ArCO2_neutron_1p07MeV_t0.root | proton | 305.89555449169535 | 0.004266565923591386 | 1.0 | 1.0

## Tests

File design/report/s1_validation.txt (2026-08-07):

==========================================================================
!! SUPERSEDED IN PART — read this first (2026-08-07) !!

This is the log of the 2026-08-06 run, kept as the record of it. Its V1, V1b,
V2, V3 and V4b results stand. Its V4 section does NOT: the "A1 REFUTED" verdict
at the bottom compared incommensurable quantities. The measured tau_g of
5.3-7.3 us is not a drain measurement at all — it is the decay of the Y-view
kernel relative to X beyond a Gaussian toy model, fitted on a <=1.4 us window
where any decay common to both views cancels by construction and an ms-scale
drain is invisible.

A1 (ESL strips contacting copper bus at both y-ends and nowhere between) is
CONFIRMED hardware, and a drain-free kernel reproduces the apparent tau_g.
See design/RESPONSE_SIM_PLAN.md §1 and §3, and
response/validation/tau_g_reinterpretation.py. Production default is
tau_drain_s=None.

V4 has since been redefined (plan §3) and passes at charge level.
==========================================================================

==========================================================================
S1 weighting-potential solver — acceptance tests
gap 150 µm (confirmed) | ESL 550/250 µm on 800 µm | pads 780 µm | superperiod 31.2 mm
==========================================================================

V1  uniform sheet vs closed form
       t =      0.0 ns   max|num-ana|/max|ana| = 2.505e-16
       t =      1.0 ns   max|num-ana|/max|ana| = 2.505e-16
       t =     10.0 ns   max|num-ana|/max|ana| = 2.505e-16
       t =    100.0 ns   max|num-ana|/max|ana| = 2.647e-16
       t =   1000.0 ns   max|num-ana|/max|ana| = 8.641e-16
       (4.3 s for 5 times on a 256x780 grid)
  [PASS] V1 uniform sheet vs closed form                      8.641e-16 (tol 1.0e-02) 

V1b small-k limit -> Gaussian diffusion
       c' = 4.7222e-07 F/m^2   D = 1/(rho_s c') = 2.118 m^2/s
       plan §3 quotes c' ~ 5e-7 F/m^2 and D ~ 2.0 m^2/s
       relaxation of a  130 µm feature:     4.0 ns   (plan says ~8 ns)
       relaxation of a  800 µm feature:   151.1 ns   (plan says ~300 ns)
  [PASS] V1b decay rate -> k^2/(rho_s c')                     2.159e-04 (tol 1.0e-02) 

V2  isolated strip, k_y = 0, telegraph behaviour
       39 strips resolved on the grid
        t [ns]      total (k=0)      structure (mean std WITHIN a strip)
             0.0     5.862500e+01     5.782801e-03
             1.0     5.862500e+01     5.341714e-03
            10.0     5.862500e+01     3.152066e-03
           100.0     5.862500e+01     1.300587e-04
          1000.0     5.862500e+01     1.198308e-04
         10000.0     5.862500e+01     1.198308e-04
       charge conservation |q(10 µs)/q(0) - 1| = 0.000e+00
       structure relaxation std(10 µs)/std(0) = 2.072e-02
       Charge in a 250 µm insulating gap, and charge on a strip with no y-gradient,
       both have NO DC path to ground. That asymmetry between x (blocked) and
       y (conducting) is the geometric origin of the measured X/Y sharing
       difference — plan §1.

       grid convergence of the residual (must fall ~1/nx):
         nx     µm/sample   struct(10 µs)/struct(0)
          390      80.00      3.8031e-01
          780      40.00      1.2365e-01
         1560      20.00      4.6105e-02
         3120      10.00      2.0722e-02
       ratio per doubling: 3.08, 2.68, 2.22  (first order -> ~2)
       => a production run needs <=10 µm sampling in x, which is what plan §2
          already specifies for the export grid.
  [PASS] V2 strip charge conserved (no drain term)            0.000e+00 (tol 1.0e-06) 
  [PASS] V2 residual converges at >= first order              0.000e+00 (tol 1.0e-09) (ratios 3.08, 2.68, 2.22)

V3  prompt limit, late-time limit, no growing modes
        t [ns]      sup|Psi|
             0.0   8.863827e-01
             1.0   8.752916e-01
            10.0   6.575547e-01
           100.0   1.230790e-01
          1000.0   1.136966e-02
  [PASS] V3 prompt via propagator == S/C direct               2.505e-16 (tol 1.0e-10) 
  [PASS] V3 uniform sheet -> grounded conductor               2.924e-73 (tol 1.0e-06) 
  [PASS] V3 no growing modes                                  0.000e+00 (tol 1.0e-12) 

V4b explicit drain term
        t/tau      sup|Psi| / prompt      exp(-t/tau)
           0.0     1.000000e+00     1.0000e+00
           1.0     3.743632e-01     3.6788e-01
           3.0     9.604740e-02     4.9787e-02
          10.0     2.269986e-03     4.5400e-05
          30.0     4.198665e-06     9.3576e-14

       C(k) at the 250 µm gap scale is 2.20x its k->0 value,
       so gap-stranded charge drains ~2.2x slower than charge on the strips.
       PREDICTION: the late-time tail is two-component, not a single
       exponential — a fast strip component and a slower gap component. Worth
       looking for in the measured tau_g fits, which currently assume one.
  [PASS] V4b drain empties the sheet by t = 30 tau            4.199e-06 (tol 1.0e-03) 

V4  global drain: assumption A1 vs the measured tau_g
        rho_s      tau(A1, L=412 mm)    ratio to measured 5.3-7.3 µs
        0.5 MΩ/sq        4.061 ms      x645
        1.0 MΩ/sq        8.122 ms      x1,289
        2.0 MΩ/sq       16.243 ms      x2,578
        5.0 MΩ/sq       40.608 ms      x6,446

       Even at the most favourable corner of the resistivity scan, A1 predicts a
       drain three orders of magnitude SLOWER than what is measured.
       to get 6.3 µs at  0.5 MΩ/sq the strips would have to be grounded
         every   16.2 mm — not every 412 mm.
       to get 6.3 µs at  1.0 MΩ/sq the strips would have to be grounded
         every   11.5 mm — not every 412 mm.
       to get 6.3 µs at  2.0 MΩ/sq the strips would have to be grounded
         every    8.1 mm — not every 412 mm.
       to get 6.3 µs at  5.0 MΩ/sq the strips would have to be grounded
         every    5.1 mm — not every 412 mm.

       CONCLUSION: A1 as literally stated is refuted by the data.
       Candidate explanations, in the order worth testing:
         (a) the strips are not the drain path at all — the measured tau_g may be
             the pad-plane/front-end RC rather than sheet transport;
         (b) there is a conductive path at a much finer pitch than the active width
             (a grounding grid, or the paste contacting the bus through vias);
         (c) rho_s is far below the scanned 0.5-5 MΩ/sq.
       Until this is settled, the solver's tau_drain_s is an EXPLICIT INPUT and the
       production scan should carry it as a nuisance parameter pinned to the
       measurement, not derived from A1.
  [FAIL] V4 A1 reproduces measured tau_g (EXPECTED FAIL)      2.809e+00 (tol 3.0e-01) <- refutes A1, see above

==========================================================================
solver correctness : 5/5 passed
physics assumption : A1 REFUTED by the measured drain time

  A1 being refuted is a RESULT, not a bug. It means the ESL
  strips are not drained through their y-ends alone. The solver
  is correct either way: it takes tau_drain_s as an explicit
  input, so the production scan can be pinned to the measured
  5.3-7.3 µs while the mechanism is worked out.
==========================================================================

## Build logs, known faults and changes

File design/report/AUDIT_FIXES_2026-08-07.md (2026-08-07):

# Audit fix work order — 2026-08-07

Companion to `AUDIT_2026-08-07.md` (the findings) — this file is the implementation spec.
Audience: an implementing agent who has NOT read the audit conversation. Every fix gives the
context, the exact location, the change, an acceptance criterion, and the traps. The
undershoot fix (P6) is ALREADY DONE (`response/dream/shaper.py`, `--pzc-residual`) — do not
redo it.

## Ground rules (read before touching anything)

1. Read `design/RESPONSE_SIM_PLAN.md` §0a and `design/report/AUDIT_2026-08-07.md` first.
2. **Compute policy (plan §10)**: this laptop is orchestration-only. The LUT rebuild (Fix 1),
   any S1 re-solve (Fix 11), and Stage B re-runs go to the **desktop** (`ssh desktop`,
   62 GB); EOS access from the desktop is `rsync … lxplus:/eos/…` with a live Kerberos
   ticket (`klist`). The S3 raw slices (Fix 7) live on EOS and should be processed **on
   lxplus**, not pulled locally (19 GB).
3. **The §9 firewall stands**: nothing here is tuning. Fix 1 will move the halo numbers —
   re-running the ρ_s table afterwards is a *prediction update* and must be recorded as
   such, not iterated against the measured values.
4. **Process rule (plan §0a)**: never re-derive channel indexing ad hoc. Certify new code
   against the solver's own helpers (`kernels.charge_budget_y/_x`, `sum_over_rows`,
   `sum_over_columns`) — four ad-hoc re-derivations were wrong in one day.
5. Several agents share this repo and this machine. `git log` before editing C++; check
   `free -g` before blaming a hang on your own code.
6. After each fix, run the acceptance test named for it, and correct the plan text where the
   fix list says so (the plan is the authority document — plan §0a header).
7. Suggested commit granularity: one commit per numbered fix, message stating what physics
   or bookkeeping changed and what test now guards it.

Order of work: Fixes 2–5 and the C-list are laptop-scale and independent — do them in any
order. Fix 1 (desktop, LUT rebuild + re-runs) after the mechanical fixes so the re-run
picks everything up at once. Fixes 6–7 gate the P1 gas switch, not the current dry chain.

---

## Fix 1 — Rebuild the induction LUT with a window that covers the DAQ frame  [MAJOR]

**Context.** `response/digitizer/kernel_lut.py:47` defaults `t_max_ns=1000.0`. The S1
product is solved out to 10 µs; the DAQ area window is 32 × 60 ns = 1.92 µs (64 × 60 =
3.84 µs for the SPS config). Sheet transport feeds d=±2 on the ~0.6 µs scale and d=±3 past
1 µs (D ≈ 1 m²/s at ρ_s = 2 MΩ/sq), so truncating the kernel at 1 µs guarantees the sim
under-delivers the late halo — the same direction as the headline §9 "missing broad slow
halo" tension. Separately, the longitudinal convolutions truncate at the same edge:
`kernel_lut.py:214-221` (`apply_ion_transit` output cut to `nt`) and `:283` (`y[:, :nt]`
after the FFT convolution) drop any ion charge whose electron-current parent sits in the
last ~340 ns of the window.

**Change.**
- Raise the default `t_max_ns` to **3000** (covers the bench 1.92 µs window + ion transit
  340 ns + margin; make it a documented parameter so an SPS-config run can ask for 4200).
- Pad the two longitudinal convolutions to `nt + len(h_ion)` before truncating, so the
  *stored* window is complete rather than silently losing its own tail. The truncation to
  the output length should happen once, at the end, and be documented as "charge beyond
  t_max is deliberately outside the model".
- `response/digitizer/run.py:122-125`: bump `--n-samp` default so the frame still holds
  drift (~770 ns) + kernel (3000) + shaped tail; 4500 is safe. Update the help text, which
  currently hardcodes the 1000 ns kernel window in its arithmetic.

**Sizing trap.** The LUT build peaked at ~3.7 GB at nt=1000; expect ~3× that. Build on the
**desktop**. Also re-check the plan §0a note that "opening t_max makes it worse at fixed
n_side": that observation was charge dispersing into more channels than the ±`n_side`
window holds — after this fix, verify the audit's `n_side`/`y_window_mm` still capture the
±3 channels the §9 table needs (they should: `n_side=4` ≥ 3), and record the audit numbers
at both `n_side=4` and `8` once.

**Acceptance.**
- `test_lut_vs_solver.py` still passes at its bar (the reference is windowless, so the
  residual should *shrink*).
- `test_charge_audit.py` residual: record before/after. (See Fix 4 — the reference should
  also become per-position.)
- `test_longitudinal.py` passes; add one assertion there: an impulse placed in the LAST
  ion-transit-length of the window must still conserve charge in the padded scheme.
- Then re-run the 400-muon ρ_s table (plan §7 tables) on the desktop and record how the
  d=±2/±3 area shares and the Y-view numbers move. Expectation: halo shares rise. Record
  as a prediction revision in the plan with the audit as the cause.

---

## Fix 2 — `sharing_report`: select the in-gap deposit by ESL phase, not absolute x  [MAJOR]

**Context.** `response/solver/kernels.py:356-368` wants an in-gap deposit at x = 15.6 mm,
but `nearest_column` (`kernels.py:286-291`) minimizes |x_pad − x_want| in absolute x. Near
15.6 mm the 800/780 µm beat puts both candidate pad centres (cols 35/36, x = 15.21/
15.99 mm) at ESL phase ~10 µm from a **strip centre** (production phase convention
`ESL_PHASE_CENTERED_M`: strip occupies phase < 275 µm or > 525 µm; gap centre is 400 µm).
So the plan §3 headline table's "in-gap" row, and `meta.sharing["in-gap"]` in all 12
production products, are a second ON-STRIP deposit differing only in pad-ownership parity.
The G arrays themselves are correct; `validation/tau_g_reinterpretation.py` selects by an
explicit phase cut and is unaffected.

**Change.** Add a phase-based selector: among pad centres (optionally restricted to a
parity), pick the one minimizing circular distance in ESL phase to the target phase
(gap centre = 400 µm under the centered convention). Genuinely-in-gap pad centres exist at
cols 10–21 (x ≈ 0.4–4.3 mm and 26.9–30.8 mm); the reviewer's worked example is col 16,
phase 390 µm. Have `sharing_report` print the selected column, x0, phase, and σ_s(x0) so
this class of mislabel is self-evident next time.

**Acceptance.** For the new in-gap row: `esl_sigma_profile(x0) == 0` (in gap). Physically
expect a qualitative change from the mislabeled row: a gap deposit cannot transport along a
strip, so its late redistribution within the owning view should be suppressed and the
cross-view late feed pattern should differ from on-strip; the near-identical late view
totals (0.366 vs 0.365) that flagged the bug must NOT recur. Then:
- regenerate the sharing block for the nominal production point (a re-run of `run_point`
  is ~6 min on the desktop; do NOT re-solve all 12 points — patch their meta only if cheap,
  otherwise record in the manifest that pre-fix meta carries a mislabeled sharing block);
- replace the plan §3 table's in-gap row (keep the old row struck through with a pointer to
  the audit, per house style).

---

## Fix 3 — One trigger phase per event, real ftst semantics  [MAJOR — blocks T13b/T14 timing]

**Context.** `response/digitizer/run.py:277-284` samples the X and Y planes with two
independent uniform phases (`response/dream/daq.py:107-108` draws inside `sample()`), and
`daq.py:173-174` writes `ftst = 0` for every event. Real data: one trigger, one phase,
recorded in `ftst` (values 0–5, verified nonzero/varying in
`MX17_long_run_datrun_260506_09H28_000_03.root`), and wft *uses* it:
`nTof_x17/wft/calibrate.py:311-336` builds a `dt_xy` correction keyed by `ftst_x − ftst_y`,
applied in `reco.py:270`. The sim as-is injects ~24.5 ns rms of inter-plane jitter that no
real run has and that nothing downstream can correct.

**Change.**
- Draw ONE phase per event (in `run.py`'s event loop, or better: extend `Daq.sample` to
  accept `phase_ns` and have `run.py` pass the same draw to both views).
- Derive and write ftst from that phase with data semantics. The observed 0–5 range over a
  60 ns period suggests 10 ns ticks (6 states); **verify against wft's usage and the FEU
  manual** (`~/x17/Documents/dream/221217_FeuUsersManual.pdf`) before hardcoding — the
  implementer must confirm (a) tick size, (b) whether X and Y FEUs of one event carry the
  same or independently-latched ftst in real data (check a real paired run:
  `ftst_x − ftst_y` distribution width in the det3 long run). Mirror whatever the data does.
- Thread the per-event ftst array through `daq.write_decoded` (`daq.py:152-174` already
  accepts `ftst=`, it is just never passed).

**Acceptance.** A paired-file check on sim output: distribution of (X peak-sample time −
Y peak-sample time) narrows vs before; `ftst` distribution uniform over its states and
IDENTICAL between the two FEU files if that is what data shows. Ideal closure: run wft's
`calibrate` dt_xy machinery on the sim unchanged and confirm it finds the same
phase-vs-ftst structure it finds in data.

---

## Fix 4 — Anchor the real-pad kernel; make the charge audit self-explaining  [MAJOR]

**Context.** The closed-form sum rule certifies only fictitious pitch-sized tiling pads
(`kernels.py:427-429`). The production real-pad capture 0.665023 agrees with the
semi-analytic (0.68/0.78)² × 0.875 = 0.6656 to 0.08 % — but only in a comment
(`test_charge_audit.py:118`), never asserted. `test_lut_vs_solver.py:9-16` claims the LUT
reference is "the same code path whose closed-form sum rule passes" — false:
`charge_budget_y/_x` (`kernels.py:294-316`) is separate indexing from
`sum_over_rows/columns` (`kernels.py:251, 273`). And the charge audit's +1.5 % residual is
an EXCESS the audit's own leak framings (which all predict deficits) cannot produce —
almost certainly the probe positions sampling capture above the grid mean (d=0 capture
spans 0.22–0.35 across columns).

**Change.**
- In `test_charge_audit.py`: assert
  `abs(channel_capture_prompt − (PAD_SIZE/PAD_PITCH)**2 * sum_rule_expect) < 0.005`
  (bar chosen: measured agreement 8e-4; 0.5 % leaves room for fringe fields while still
  catching any indexing-level error).
- Make the audit's reference per-position: for each probe, compute the expected capture at
  THAT (x, y) from `charge_budget_y + charge_budget_x` (total over all channels), instead
  of comparing the probe mean against the grid-mean scalar. Print per-probe residuals and
  their spread. The +1.5 % should collapse to interpolation-level; then tighten `TOL_LEAK`
  from 3 % to 1 %.
- Rewrite the `test_lut_vs_solver.py` docstring to state what it actually certifies: two
  independently-written indexings agree to 1e-4; the closed-form anchor applies to a
  different (tiling-pad) geometry; the real-pad anchor is the assert added above.

**Acceptance.** New assert passes; per-probe audit residual spread printed; a deliberately
broken parity (flip one `% 2` locally, revert after) makes the new per-position audit fail
loudly — verify it does, since the old grid-mean version was blind to redistribution.

---

## Fix 5 — Record the wet-CF₄ bracket check (the one that gates P1)  [MAJOR — data product check]

**Context.** Plan §0a's cert row "wet-CF₄ v_drift 74.32 vs 74.7 µm/ns" compares the dry
control column of the table against a published *dry* Magboltz number — dry-vs-dry.
`response/params/wet_cf4_drift.py:122-124` defines the check that matters: the wet curves
(1.0/1.5/2.0 % H₂O) must bracket the MEASURED 13–15 µm/ns at 233 V/cm, "if the wet curves
do not bracket it … nothing downstream should be run." That result is recorded nowhere.

**Change.** On lxplus (or desktop via rsync): fetch
`/eos/experiment/ntof/data/x17/response_sim/gas/wet_cf4_drift.json`, evaluate v_drift at
233 V/cm for each mixture, and record in the plan (cert table row corrected to say what is
now actually certified) AND in a small committed JSON/text under `design/report/`. Include
transverse diffusion at the same point — it is the input the halo prediction needs.

**Acceptance.** Numbers exist in-repo for all four mixtures at 233 V/cm; the plan row no
longer claims wet validation from a dry comparison. If the bracket FAILS: stop, mark P1
blocked in the plan, do not proceed with any wet-gas Stage B work.

---

## Fix 6 — Attachment through the chain  [MAJOR for P1; no-op dry]

**Context.** Plan §7 step 2 specifies survival e^(−z/λ); nothing implements it.
`response/digitizer/gas.py:53-56` interpolates only `v, dL, dT` (the dry table has no eta
key); `response/digitizer/digitize.py:139-177` (`transport`) has no survival term;
`params/wet_cf4_drift.py:96-103` stores `eta_per_cm` that nothing reads. CF₄+H₂O attaches;
attachment is z-dependent and re-weights the depth mixture that produces the c1-vs-z
diffusion signature — it cannot be folded into a flat gain factor.

**Change.**
- `gas.py`: interpolate `eta_per_cm` when present, return 0.0 when the table lacks it
  (dry tables keep working; log once which branch was taken into provenance).
- `digitize.transport`: survival probability p = exp(−eta_per_cm × z_cm) per electron;
  combine with the mesh-transparency Bernoulli into a single thinning
  (p_surv = ε_mesh × e^(−ηz)) so the statistics stay binomial and the truth accounting
  sees one loss channel with two named factors.

**Acceptance.** With the dry table: bitwise-identical results at fixed seed (η = 0 path).
With a synthetic table carrying constant η: measured survival vs z matches exp(−ηz) over
the 30 mm gap to statistical precision, and c1-vs-z reweighting moves the right way
(deep/high-diffusion clusters suppressed).

---

## Fix 7 — Recover the avalanche survival factor from the S3 raw slices  [MAJOR — feeds P2]

**Context.** Plan §5's "avalanche size cap bites" is false — there is no cap
(`--max-avalanche` defaults to 0/uncapped, `avalanche/mx17_aval_calib.py:96-98, 185-186`);
the falling nev column is the deliberate per-voltage schedule in `mx17_aval_points.txt`.
The REAL defect: `avalanche/collect.py:38` fits the Polya on `g[g > 0]` (conditional on
survival), the per-slice `survival` field present in each raw JSON
(`mx17_aval_calib.py:293`) is dropped by `reduce_file`/`merge`, and
`digitize.py:176` applies that conditional Polya to every mesh-surviving electron. Per-
electron charge is biased high by 1/P(g>0), magnitude unknown from the shipped calib.
Direction feeds P2 (16.5 % ADC saturation).

**Change.**
- On **lxplus** (raw is 19 GB on EOS `response_sim/avalanche/raw/`): extend `collect.py` to
  carry `survival` (per V, with its binomial error) into the merged calib → bump to
  `aval_calib_v3.json`, keep v2 untouched on EOS.
- `digitize.py`: Bernoulli-thin each electron by `survival(V)` BEFORE the Polya draw (this
  is exactly the conditional-distribution decomposition, so the existing conditional Polya
  stays correct as-is). Wire the value from the calib; refuse to run silently if the calib
  lacks the field (explicit warning + survival=1 with provenance tag).
- Correct plan §5's cap sentence (T7 row too).

**Acceptance.** Two routes to mean charge per drifted electron agree:
survival × mean(conditional Polya) vs the direct mean over all seeds including zeros
(computable from raw during the collect run — assert it there). Record survival(490 V) and
the resulting change in the P2 saturation fraction in the plan.

---

## Fix 8 — Name decoded output by the target run's FEU ids  [MAJOR for T14 mechanics]

**Context.** `run.py:374` writes `sim_decoded_07.root` (X) / `_08.root` (Y); the det3
detector the chain mimics is x→FEU **3**, y→FEU **4** (run.py's own comment at 221-229,
det3 `run_config.json`, and the real det3 decoded files `*_03/_04.root`). In wft the file
suffix IS the FEU id (`wft/io.py:39-41`) and keys the strip map; `feus=[7,8]` in
`qa_config.py` is a different physical detector (mx17_2). Left as-is, a det3-configured wft
finds no files; "fixed" by renaming, it inherits the wrong strip map.

**Change.** Add `--feu-ids X_ID Y_ID` (default `3 4` for the det3 bench) controlling both
the filenames and any in-file FEU identification; update `--decoded-out` help text and
`test_daq_wft.py` accordingly. Document in the plan (P5/§8) that the default now matches
det3 and that an SPS-run comparison must set the ids from that run's config.

**Acceptance.** `test_daq_wft.py` passes with the new default names; a wft io smoke read
with a det3-style `feus=[3,4]` config discovers both files.

---

## C-list — smaller but real (one commit each unless trivial)

**C1. Noise scale bias (~3.7 % loud).** `response/dream/noise.py:186-189`: per-channel
traces are generated from the channel-averaged spectrum then scaled by
`sigma_chan / median(sigma_chan)`. The generated trace's rms is the Parseval rms of the
mean spectrum (root of MEAN variance), not the median sigma; the sigma distribution is
right-skewed, so everything is +3.7 %. Fix: divide by the Parseval rms of `amp_chan`
(compute it once from the amplitude spectrum, same convention as `_coloured`). Acceptance:
`noise.selftest()` per-channel residual drops from ~3.5 % to <1 %; tighten its tolerance.

**C2. X-view one-pad-off booking (~1.3 % of avalanches).**
`response/digitizer/digitize.py:195` derives `col` from the true x while
`kernel_lut.py:80-88` defines band offsets relative to the nearest 40 µm LUT sample; every
second pad boundary falls between the two conventions. Fix: derive the column from the SAME
folded LUT sample used for the kernel (one line). Acceptance: extend `test_lut_vs_solver`
with probes at pad-boundary ± 5 µm drawn OFF the LUT grid, comparing against
`charge_budget_*` at the probe's true position: the d-profile must not shift by a whole pad
for any probe.

**C3. Packet-mode Polya variance.** `digitize.py:166-176`: one single-electron Polya draw
scales the whole packet → variance n² Var(g) instead of n Var(g). Fix: draw the packet gain
as `rng.gamma(shape=n_surv*(1+theta), scale=gbar/(1+theta))` (sum of n independent Polyas).
Production `packet=False` is unaffected; fix before profiling §12 item 11. Acceptance: for
n=100 packets, packet-mode charge variance matches per-electron mode to a few %.

**C4. `charge_budget_x` y-fold.** `response/solver/kernels.py:313`: `argmin(|sx.y − y0_m|)`
clamps out-of-box y to the edge. Fold y0 into the 1.56 mm box (mod, mirroring
`charge_budget_y`'s x-fold at `:302`). Acceptance: `charge_budget_x(..., y0_m=5e-3)` equals
`charge_budget_x(..., y0_m=5e-3 % box)` exactly.

**C5. `lut.ix()` seam wrap.** `kernel_lut.py:149-152`: nearest-sample lookup clips at the
superperiod edge; the last half-stride should wrap to x[0] (circular metric mod 31.2 mm).
Also add one probe in `test_lut_vs_solver` that goes THROUGH `ix()` (the current test
bypasses it with argmin). Acceptance: a source at 31.19 mm maps to the x[0] sample.

**C6. ny convergence certificate.** ny=512 (97.5 µm) leaves the PROMPT kernel's pad-edge
shoulder in y wrong by up to ±0.028 absolute (≤5e-4 late; 0.003 after a 150 µm diffusion
smear). One-off, desktop: re-solve the nominal point at ny=1024, difference the prompt
kernels, store the result as `test_ny_grid`-style evidence (mirror `test_time_grid.py`).
If the smeared error is confirmed ≤0.3 %, keep ny=512 with the certificate recorded; if
not, the production grid needs ny=1024 (≈2× cost, still minutes/point).

**C7. Amp-gap/groove clusters.** `digitize.py:158` clips z<0 to 0 and then gives those
clusters full-gap gain AND mesh transparency, contradicting `clusters.py:20-24`. ~0.5 % of
track length, ~9× overweight, prompt and unshared. Decide and implement ONE of: (a) drop
amp-gap clusters with a provenance note (defensible: sub-percent), or (b) partial gain
G_partial = exp(ln(G) · z_birth/gap) with NO mesh transparency for them. Either way make
`clusters.py`'s contract and `digitize.py` agree. Acceptance: a synthetic ClusterTree with
only amp-gap clusters produces the documented behaviour.

**C8. Fano factor — decide.** Plan §7 step 1 specifies F≈0.2; neither stage implements it
(Stage A: `SteppingAction.cc:79-82` floor+Bernoulli; Stage B refuses to re-derive). Either
implement in Stage A (per-cluster n from a truncated Normal(n̄, √(F·n̄)) — cheap, keeps
Stage B untouched) or de-scope with a plan edit stating resolution-type observables are
simulated slightly narrow. Do not leave the plan promising what the code doesn't do.

**C9. Truth block.** Plan §7 step 7 requires per-event truth (true (x,y) incl. the run.py
offsets, t0, per-channel true charge, electrons lost to mesh/survival). Write it as a
sidecar parquet/npz next to `--decoded-out` keyed by eventId. Acceptance: eventId join
between truth and decoded files is total.

**C10. Keep empty events.** `run.py:264` `continue`s zero-electron events before the DAQ
buffer, so decoded files omit triggers real runs record — breaks occupancy comparisons and
eventId alignment. Write noise-only frames for them (they still get pedestal+noise).

**C11. Gas table path.** `gas.py:37` hardcodes `~/PycharmProjects/nTof_x17/...` — breaks
condor. Make it a parameter with env-var override; embed the table's path AND a content
hash in provenance.

**C12. Stale analytic-ion default.** `digitize.py:98` `z_aval_um=5.0` — the S3 v2
measurement says 13.84 µm (mean ion birth height). Update the default and note that
`--ion-model analytic` now reflects v2; the measured template remains production default.

**C13. Portability/robustness nits.** `spread.py:148` `sp.ptp()` → `np.ptp(sp)` (removed
from ndarray in NumPy 2.x). `manifest.py:95-97` formats `None` with `:9.1e` and dies if a
product lacks the sum-rule block → print `FAIL/absent` instead. `wpot.py:247` `_eig_cache`
is dead — delete it, and (optional, free 2×) reuse the eigendecomposition for −k_y (M
depends on k_y² only).

**C14. Stage A tidy-ups** (all MINOR, from the C++ review): `EventAction.cc:35,37` divides
by eV twice in the verbose print (1e6 off; files unaffected). `mm_sim.cc:159-163` vs
`macros/run_default.mac`: supplying the macro runs zero events (no beamOn) while the macro
header claims otherwise — make `main()` issue beamOn after a macro that lacks one, or fix
the macro/header. `RunAction.cc:178-196`: Meta branch addresses point at block-scope locals
— hoist to function scope. Record the primary vertex (x,y) in the EventTree so
`--beam-spread` truth is exact, and stop `run.py` double-randomizing when the Geant4 file
already carries a spread (detect via Meta or a provenance flag; today's default re-offsets
in post and mislabels provenance, statistically benign but wrong bookkeeping). Add the
missing fiducial handling: clamp/flag `col,row` outside 0..511 in `digitize.py:195-196` so
the budget and decoded paths agree on out-of-area delta rays.

**C15. ZS bookkeeping.** Code (`ZsChkSmp=1`) matches det3's config; plan §8.5's "ZsChkSmp=4"
is the July-beam setting — fix the plan line, and parameterize ZsChkSmp from the run config
rather than a constant if ZS is ever switched on. Verify whether firmware keeps pre-samples
before any ZS-mode comparison (unverified in the audit).

---

## Plan-text corrections (no code) — do in one commit

In `design/RESPONSE_SIM_PLAN.md`:
1. §5 / T7: remove the "avalanche size cap bites" explanation (no cap exists; nev follows
   `mx17_aval_points.txt`); note the survival-factor issue and its fix (Fix 7).
2. §8 step 5: "saturation at 3550" → clip is 0..4095 (data reaches 4095); 3550 is wft's
   censoring threshold on pedestal-subtracted W (`wft/model.py:57`).
3. V5: reconcile §0a "certified 7.8e-7" with T5 "V5 still not run" — the script EVALUATES
   exp(−2πng/p); call it an analytic bound, not a test, in both places.
4. Cert table: label the noise round-trip, ADC end-to-end, and ion A/B rows as
   internal-consistency checks (not data anchors), and replace the "98.0 vs 102.4" row —
   that gap was the test contaminating its own pedestal with injections
   (`test_daq_wft.py:55-64`); with clean pedestal events the scale closes at 102.0/102.4.
   Optionally fix the test: use signal-free events for the pedestal estimate, then tighten
   its 10 % tolerance (it would currently pass a +13 % gain error).
5. Per-product sum-rule scope: `kernels.py:492-493` certifies t ≤ ~0.2 ns at reduced grid;
   either extend `times[:6]` to a spread of the full axis (cheap) or say so in T5.
6. P5: the connector-inversion ambiguity is resolved — `Mx17StripMap.apply_orientation`
   reverses per connector (64 ch), unconditionally; the sim's deliberate identity mapping
   stays, but the plan should stop calling it unresolved.
7. V2's description: it tests charge conservation + convergence order (per its docstring),
   not the Galan closed form §3 names.
8. §3 in-gap table row: superseded by Fix 2's regenerated numbers.
9. x/y sign convention (`ActiveAreaFrame.hh:29-38` placeholder): still OPEN — leave open,
   but add the audit's note that a flip inverts checkerboard parity AND the 31.2 mm beat
   phase, and that the beat phase vs absolute channel number at T14 is the in-data check.

## Explicitly NOT in scope here

- T10 slow path (ion lateral shape, P3), T6 field-map export (P4), V6 — tracked in the plan.
- Any comparison against §9 numbers beyond recording how predictions moved (firewall).
- The undershoot (done). β stays a scan parameter until T14.

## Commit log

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2026-08-06 Document as-built MX17 geometry from mechanical CAD
    Extracted the detector stack from the Solid Edge STEP assembly and compared
    it against both Geant4 models. Records the aluminium gas frame (440 outer,
    410 aperture, 30 mm - it is the drift-gap spacer), the 8 mm aluminium backing
    plate that neither sim has, and the 5 mm gas gap between window and cathode.
2026-08-06 Add geometry implementation brief; correct CAD comparison table
    Work order for merging the MX17_Geant and MX17_Full_Geant detector
    descriptions and applying the geometry fixes. Records two places where the
    CAD is incomplete rather than the sims being wrong (drift copper cladding,
    window aluminization), a foil missing from every source (aluminized mylar
    behind the rohacell), and ports of the p2_geant pressure-bulge and
    woven-micromesh models. Lists the eight inputs still needed.
2026-08-06 Merge MM/PCB stack into shared MX17ModuleGeometry.hh (pure refactor)
    One source of truth for the module layer stack, consumed by both MX17_Geant
    and MX17_Full_Geant (relative-path include). LegacySpec reproduces the
    previous geometry exactly: fixed-seed runs of all six SimModes are
    bit-identical to the pre-refactor build (300-event digests, full precision).
    Placement keeps the historical per-slab running-z arithmetic so positions
    are bit-for-bit unchanged; ModuleSpec already carries the as-built knobs
    (applied in a follow-up commit).
2026-08-06 Apply as-built MX17 module geometry (CAD + confirmed inputs)
    AsBuiltSpec is now the default for all MM modes (--legacy-geometry restores
    the old stack; fixed-seed legacy runs remain bit-identical):
    - Mylar window 40 -> 60 um (CAD), 440x440, 0.1 um Al on the drift side
    - 5 mm window-flange gas gap (Al ring 440/400.2) between window and cathode
    - Terraced-dome front-window bulge over the 400.2 mm free span; default sag
    8 mm from a Hencky estimate at ~3 mbar overpressure (--bulge-front)
    - Drift cathode 406x406 copper-clad kapton; Al gas frame ring 440/410 x 30 mm
    is the drift spacer (kapton->mesh = 30.000 mm, Cu cladding inside)
    - 4x field-cage PCBs (1.62 mm FR4) lining the 410 mm aperture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
2026-08-06 Document the as-built geometry upgrade
    - Correct GEOMETRY_FROM_CAD.md discrepancy 1: the 8 mm support plate has a
    402x402 through-aperture in the STEP (the 'verified solid' claim was a
    parser error that missed the inner face bounds); aperture is concentric
    with the 399.36 mm active area, the 470 mm plates are offset (+15,+15)
    - Mark the implementation brief done, with the resolved-inputs table
    - Add design/NEEDED_INPUTS.md tracking the remaining assumptions
    - README: shared module description, as-built stack, new CLI knobs
2026-08-06 Gerber-measured copper model; flat straddling M1 cards with true stack
    Readout board copper is now the real design: the five physical gerber layers
    (L3 guard ring, L4 pads, L5 Y strips, L6 X strips, L7 fan-out; L8 is
    outline-only), each a 26 um sheet density-scaled by its measured area
    coverage over the 470 mm board face (0.095/0.651/0.419/0.420/0.456 —
    scripts/gerber/analyze_cu_coverage.py, PIL raster port of the p2 approach,
    parser copied from p2 with %LPD/%LPC polarity support). FR4 filler still
    solves the CAD 1.70 mm body. New mx17_board_copper.png renders the layers
    from the gerbers with model overlays, like p2_board_copper.png.
    M1 front-end cards corrected: they lie FLAT on the drif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
2026-08-06 M1 cards gerber-anchored; peel-back and plan-view figures; resist coat 412
    M1 rework (Dylan feedback): the M1 gerbers are drawn in the readout-board
    frame at the as-mounted position - one 41x160 card at radial 219.4..260.4,
    tangential centre +100, whose bottom pogo-pad field lands exactly on the
    board's connector copper (clusters at tangential +-83..117 on the +x/+y
    edges). Four cards, two per connector edge, laminate flat on the board with
    no standoff (1.6 mm bare-laminate guess; Mec8 and JZ pogo connectors
    omitted, NEEDED_INPUTS 6b). Cu coverage remeasured over the true card
    window. Inner edge clipped to the 440 frame ring.
    ResistivePaste widened to the 412 mm full-sheet deposit boundary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
2026-08-06 Mark §10a items 1 and 4 done, and correct the cleanup step
    The desktop's python stack was already in place: numpy/scipy/matplotlib
    were present and uproot/awkward were installed via pip --user, so item 1
    was not outstanding. Records the versions and why conda was skipped —
    PyROOT here is bound to python 3.10, so a conda 3.11+ env would have no
    PyROOT and could not use the pinned Garfield without a rebuild.
    Item 4's "safe to delete" was not safe as written: .bashrc sourced
    install_lcg110/share/Garfield/setupGarfield.sh, so deleting first would
    have broken every login shell. .bashrc now points at install/ (the
    927e5c21 pin) and the stale dirs are gone.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
2026-08-06 Merge as-built geometry: patterned readout copper + ESL strips
    Lifts the §7 coordination freeze in design/RESPONSE_SIM_PLAN.md — the
    parallel geometry effort is complete, so the response-simulation work may
    now touch C++ files.
    What landed:
    - Real 512x512 readout copper (0.68 mm pads L4, Ø0.50 mm dots + 0.098 mm
    bus traces L5/L6) and 515 discrete 550 µm ESL resistive strips on the
    0.8 mm pitch, built via nested G4PVReplica. Default ON (--patterned-readout);
    --homogenized-readout restores the density-scaled sheets and resist slab.
    - Bulk pillars (Ø0.6 mm, 4.68 mm grid) placed in the amplification gap.
    - Gerber copper-coverage measurement corrected: PIL endpoint-inclusive
    raster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
2026-08-06 Stage A (T8): cluster time, creator process, active-area frame
    design/RESPONSE_SIM_PLAN.md §6. The ClusterTree had position and energy but
    no time, which blocks the whole response chain: the drift time of every
    electron is measured from the ionisation time, so no waveform can be built
    without it.
    - ClusterTree gains `time` (globalTime at the step midpoint, ns — matching
    the midpoint already used for the position) and `creator` (the process
    that made the track, "primary" for the beam particle; §6 item 3).
    - New `Meta` tree carries the world -> active-area transform, so the
    response chain never hard-codes the module placement. Captured from the
    AmpGas placement itself, so it follo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
2026-08-06 S1 solver (T1, T3, T4, T5) + S3 campaign; A1 boundary assumption refuted
    design/RESPONSE_SIM_PLAN.md §3 and §5.
    response/common/constants.py (T1)
    Single Python source of truth for the response geometry, cross-checked at
    import against shared/MX17ModuleGeometry.hh so the two cannot drift.
    Reproduces the plan's own sanity numbers: c' = 4.72e-7 F/m^2 (plan ~5e-7),
    D = 2.12 m^2/s at 1 MΩ/sq (plan ~2.0).
    response/solver/wpot.py (T3, T4, T5)
    The semi-spectral dynamic weighting-potential solver. Layer transfer
    relations C(k), S(k); Bloch coupling of the patterned sheet; exact
    propagation by symmetric eigendecomposition (no time stepping).
    One deviation from the plan, in its fa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
2026-08-06 T2: pad->X/Y checkerboard confirmed from the gerbers (§12 item 7 RESOLVED)
    The plan asks whether the pads alternate checkerboard between the X and Y
    bus layers. They do, exactly.
    The via pattern does NOT answer it. Both bus layers carry an annular ring on
    all 512x512 pads (on the 0.78 mm grid to 0.0 um) because the via is a plated
    through hole from physical L4 to L7 and rings every layer it passes.
    What answers it is the 0.1 mm connector stub — 390 um, exactly half the pad
    pitch — from a pad's ring out to the bus:
    Y layer 131072 stubs = 512 x 256, ALL at (col+row) EVEN, bus along x
    X layer 131072 stubs = 512 x 256, ALL at (col+row) ODD, bus along y
    Zero overlap; 262030 of 262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
2026-08-07 §12 item 10 RESOLVED: the weave and 400 lpi were never in conflict
    The item assumed the pitch had to be back-solved from the fill factor. It does
    not: the header states the weave directly (19 um wire, 48 um opening, so 67 um
    pitch = 379 lpi) and derives fill = pi*d/(4*pitch) = 0.2227 as the areal-mass
    scale for a 2d-thick slab, which is the quoted 0.223.
    Against the standard 400 lpi / 18 um mesh, d/pitch is 0.2836 vs 0.2835 — the
    same weave geometry up to a uniform 5.5 % scale. Optical transparency (0.5133
    vs 0.5134) and areal mass agree to 0.04 %. The only physical difference is the
    absolute scale against the 150 um gap: pitch/gap 0.447 vs 0.423.
    So T6 uses the header per §4, and the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
2026-08-07 Bulk products live on EOS; produce the full 12-point grid
    User: the nTOF EOS allocation is effectively unlimited, so use
    /eos/experiment/ntof/data/x17. §2's canonical bulk store is now
    /eos/experiment/ntof/data/x17/response_sim/{s1,s2,avalanche/raw,clusters,currents};
    the laptop's ~/x17/response_sim is a working copy, not the archive.
    Two routing facts worth writing down because they are not symmetric:
    * the desktop can reach lxplus and READ eos but cannot WRITE it — a bare
    ssh desktop -> lxplus carries no AFS/krb token (it cannot read .bashrc)
    and eos writes fail with "Operation not permitted". Desktop products
    route desktop -> laptop -> EOS.
    * drain on a .done marker w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
2026-08-07 CORRECTION: withdraw the tau-based rho_s conclusion; measure spread instead
    I reported earlier today that the measured tau_X ~ 230 ns / tau_Y ~ 410 ns sit
    at the TOP of the scanned rho_s range, nearest 5 MOhm/sq, and put a note in §12
    item 1 saying to extend the scan above 5. That was wrong. Both are withdrawn.
    The estimator was unsound. tau_1e is the time for the d=+1 neighbour to cover
    1-1/e of the way from its prompt value to its MAXIMUM, but with
    tau_drain_s=None the sheet conserves charge and the kernel never saturates, so
    the "maximum" is simply the value at the 10 us window edge. The whole quantity
    is a function of where the window was cut. It survived scrutiny at d_k=75 only
    by coi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
2026-08-07 T9 Stage B skeleton + T6 first-pass mesh transparency
    Stage B (response/digitizer/): gas.py reads the Magboltz drift table,
    kernel_lut.py turns an S1 product into a uniform-time windowed current lookup,
    digitize.py runs clusters -> drift -> mesh -> avalanche -> induced current,
    selftest.py exercises it on synthetic deposits before Geant4 is in the loop.
    Two design decisions worth recording, both forced by numbers rather than taste:
    * electrons are transported INDIVIDUALLY, not as per-cluster packets. The
    three lateral scales at the bench point are sigma0 = 33 um (T7),
    sigma_p = 222 um (T2b) and drift diffusion = 826 um (Magboltz, 333 V/cm
    over 30 mm). Diffusion dominates and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
2026-08-07 Digitizer LUT: restructure so it fits in memory (9.4 GB -> 1.9 GB)
    The first version resampled every stored kernel onto the 1 ns grid. That does
    not shrink a 2.3 GB product, it inflates it: the 40 X kernels alone would be
    40 x 3001 x 32 x 3120 float32 = 48 GB, and the build reached 9.4 GB resident on
    a 16 GB laptop before being killed.
    Three cuts, each justified by what the digitizer can resolve rather than by
    convenience:
    * x decimated 4x (10 -> 40 um). Every avalanche is smeared by ~826 um of
    transverse diffusion before it lands, so 10 um sampling carries nothing the
    digitizer can use. It stays in the PRODUCT, where the 31.2 mm beat and the
    ESL strip edges need it.
    * y wi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
2026-08-07 T9 runs end to end: c1 = 0.20 predicted against 0.23-0.28 measured, untuned
    Stage B now produces the plan §9 headline observable from first principles.
    Integrating over clusters uniform in z across the 30 mm gap gives a track-level
    c1_X = 0.202 against the measured 0.23-0.28, with nothing tuned to reach it:
    the kernel came from S1, the gain and sigma0 from the S3 campaign, the
    diffusion from the Magboltz table, all fixed before this ran. The remaining
    ~15 % is the right size for what is still missing — ion tail, DREAM shaping,
    and the fact that the measured number comes out of the full wft chain rather
    than off a charge integral.
    The z dependence is the real evidence. c1_X rises 0.005 ->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
2026-08-07 S3: the empty i_elec/i_ion explained and fixed; analytic ion term added
    ROOT CAUSE of the identically-zero current shapes in all 56 campaign slices.
    Both AvalancheMicroscopic and AvalancheMC default to m_useWeightingPotential =
    true, i.e. they compute the induced current from the weighting POTENTIAL, not
    from the weighting field. ComponentConstant has no weighting potential until
    SetWeightingPotential() is called, and the campaign only ever set the weighting
    FIELD. So WeightingPotential() returned 0 everywhere and every signal came out
    zero — silently, with the avalanche and the ion drift both running perfectly
    normally, gain and sigma0 unaffected. Verified on the desktop:
    wpot unset, U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
2026-08-07 T7 corrected to PARTLY DONE: the S3 current shapes were empty
    I marked T7 done. Gain, Polya theta and sigma0 were fine, but i_elec/i_ion were
    identically zero in 56/56 slices and I did not check them before closing the
    task. Corrected, with the root cause and the fix recorded in §5, and the
    campaign re-thrown into results_v2/.
    Also records the near-miss: the first weighting-field probe returned zero and
    looked conclusive, but it had omitted SetMedium and ComponentConstant zeroes
    its weighting field where there is no medium. The field was correct all along.
    Post-fix smoke test reproduces the analytic ion transit independently — a
    1740-bin (348 ns) ion tail against g^2/(mu V) = 306 ns.
    C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
2026-08-07 Stage A -> Stage B wired up; T6 transparency folded in
    clusters.py reads a Geant4 ClusterTree through the Meta world->active-area
    transform. Going through it is not optional: in the 2026-08-07 production the
    drift gas sits at world z in [-12.5, +17.5] mm, so a digitizer that took world
    z as "drift distance from the ESL" would hand NEGATIVE depths to the diffusion
    model over half the gap and misplace the rest — quietly. Transformed, the gas
    maps to z in [0, 30.2] mm, ESL at 0 and cathode at 30, which is what §7 wants.
    Verified on the first real production: 500 muons, 40341 clusters, 337 primary
    electrons per event over the 30 mm gap — the right order for argon.
    Mesh transparency now co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
2026-08-07 Digitizer induction 5.8x faster — it was memory layout, not the python loop
    I said the per-avalanche python loop was the bottleneck and rewrote the
    accumulation as a vectorised bincount scatter. Measuring showed that was wrong:
    the rewrite is numerically identical (5.1e-08 relative, pure float32 rounding)
    but was 20 % SLOWER at 400 avalanches, because it materialises int64 index
    arrays that are twice the volume of the values themselves.
    The actual cause was the LUT's memory layout. With time stored as the
    slowest-varying axis, reading one channel's time series strided ny*nx floats —
    491 kB — between consecutive samples, so 1001 samples touched 1001 separate
    cache lines spread over 503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
2026-08-07 T9 track level on real Geant4 muons: c1_X = 0.201 vs 0.23-0.28 measured
    500 normal-incidence 4 GeV muons, 337 primary e-/event, through the full chain
    at 93 ms/event. c1_X = 0.201, c1_Y = 0.163 against the measured 0.23-0.28, and
    X/Y charge balance 0.506/0.494 against 0.49/0.51 — untuned, every input fixed
    before the run. The deficit is the right size and sign for the ion tail, DREAM
    shaping, ZS and noise, none of which are in yet.
    Found and fixed a trap in Stage A that would have poisoned any positional
    observable. The gun is a PENCIL BEAM at (0,0), and 512 pads is even, so the
    active-area centre sits exactly on a pad BOUNDARY. Every muon then lands where
    "the channel with the most charg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
2026-08-07 Stage A: --beam-spread, so the gun stops landing on a pad boundary
    The gun was a pencil beam at (0,0) with no way to spread it. That is a trap for
    any position-dependent readout study: 512 pads is even, so the active-area
    centre falls EXACTLY on a pad boundary and every primary lands where "which
    channel has the most charge" is a coin flip. In the first Stage B run over real
    tracks it split 216/256 and manufactured a 3x X-view asymmetry (d=-1: 0.308 vs
    d=+1: 0.093) that had nothing to do with the detector.
    --beam-spread <mm> spreads the impact point uniformly over a square. Default
    stays 0 so every existing use is unchanged. For response-chain runs use at
    least 31.2 mm, the ESL/pad superper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
2026-08-07 T11: DREAM shaper from the manual, with the register decode that matters
    response/dream/shaper.py builds the analogue chain from the manual and
    CosmicTb_MX17.cfg rather than from assumption. Self-check closes exactly:
    a delta of charge gives a 5%->100% rise of 180 ns against the manual's 180 ns.
    Three things the manual settles that were not obvious:
    * Table 9's peaking times are quoted 5%->100%, NOT 0->peak. Treating 180 ns
    as 0->peak gives tau = 90 ns instead of 98.9 ns, a 10 % error that makes
    every simulated pulse too slow. tau is solved for, not assumed.
    * THE GAIN IS NOT IN REGISTER 1. It is per-channel in state6/state7, 2 bits
    each: "done channel by channel with two 6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
2026-08-07 Compute policy: the laptop is for orchestration, not for real work
    User, 2026-08-07: outsource real compute to the desktop or lxplus. Recorded in
    §10 as a constraint rather than a preference, because it already cost time
    today.
    The digitizer LUT build peaks at ~3.7 GB and a Stage B run on top needs ~5 GB.
    On a 16 GB laptop that only works if nothing else is running — and it usually
    is: several agents share this repo and this machine, and a parallel
    scripts/gerber/extract_readout_pattern.py was holding 9.9 GB of 15 GB. Three
    consecutive Stage B runs were OOM-killed before I looked at free -g. The
    failure mode is a zero-length output file with no traceback, which reads
    exactly like a hang,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
2026-08-07 Report the impact-point sampling truthfully
    --fixed-position means "add no post-hoc offset". That is CORRECT when Stage A's
    gun already randomised via --beam-spread, and wrong only for a genuine pencil
    beam. The old message asserted "FIXED (pencil beam, on a pad boundary)" either
    way, so every run over a spread production was mislabelled as the degenerate
    case it was specifically built to avoid. Now it measures the sub-pitch spread
    and says which of the three situations it is actually in.
    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
2026-08-07 First waveform comparison: rho_s CANNOT reconcile area and peak — T10 is why
    Full chain over the rho_s scan, 400-600 muons per point. The result is
    negative and more useful for it.
    rho_s 0.5 1.0 2.0 5.0 measured
    peak +-1 X 0.373 0.342 0.320 0.295 0.16-0.19
    area c1 X 0.169 0.159 0.152 0.144 0.23-0.28
    The data's neighbour has ~3/4 the AREA of the centre but only ~1/6 the PEAK —
    charge spread over a long time. Ours arrives too fast and too concentrated. The
    obvious lever was rho_s, and it does push both the right way, but over a FACTOR
    10 the peak ratio moves only -21 % and the area moves the WRONG WAY. Pushing
    rho_s further trades area fo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
2026-08-07 Ion folding: fix a charge-non-conserving running mean, and use the measured shape
    Two changes, one of which invalidates yesterday's Stage B numbers.
    1. apply_ion_transit normalised its leading edge by samples-so-far,
    c[n]/(n+1), instead of by the rectangle length, c[n]/L. The ion delivers
    f_i/T per unit time from birth, so for t < T the answer is
    (1/T) * int_0^t x = c[n]/L. The bug inflated the first T = 340 ns by up to
    340x and put 5.9 units of charge on the readout per unit induced.
    It does not cancel from inter-channel ratios: it is a TIME-dependent
    distortion, and channels peak at different times because resistive
    spreading delays the neighbours. So every Stage B r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
2026-08-07 Report peak TIME and relative width — the observables that discriminate mechanism
    Area and peak ratios can both be matched while the arrival TIMING is wrong, and
    timing is what resistive spreading actually controls. Two additions:
    t_peak_shift_ns the neighbour's peak time minus the central channel's.
    §9 quotes this directly: +54-61 ns median for d=+-1.
    width_rel (area_d/area_0)/(peak_d/peak_0) — how much broader the
    neighbour's pulse is than the central one. Needs no
    absolute calibration and survives any per-channel scaling.
    The measured pair (neighbour at ~3/4 the area, ~1/6 the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
2026-08-07 Plan: withdraw the rho_s conclusion, record what the corrected scan says
    The 2026-08-07 "rho_s cannot reconcile area and peak" result is withdrawn -- it
    ran through the charge-non-conserving ion filter. Redone, the conclusion
    inverts: rho_s moves both Y observables toward the data at once.
    Three findings replace it:
    * The X view does not respond to rho_s AT ALL, and that is the 1-D ESL strip
    geometry rather than a bug (G_X differs 42 % between rho_s, I_X 11 %; the
    dependence is there and simply does not reach the inter-channel budget).
    It predicts an X/Y sharing asymmetry the data does not show.
    * The dominant discrepancy is the neighbour pulse SHAPE: ours is the same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
2026-08-07 Magboltz for the gas the §9 targets were actually taken in
    Ar/CF4/iC4H10 88/10/2 + water at CERN pressure, scanning 1.0/1.5/2.0 % H2O
    around the data-side bracket of 1.3-1.7 %, with the dry point kept as
    reference. Reports transverse diffusion, which is the piece nTof_x17's existing
    wet files lack and the piece Stage B actually consumes: dT sets the lateral
    spread at the mesh and therefore the whole sharing budget.
    The water fraction is scanned rather than assumed because drift is an open item
    already quoted three incompatible ways, and a single value would hide the
    sensitivity.
    Prints its own validation point: the wet curves must bracket the measured
    13-15 um/ns at 233 V/cm against a dry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
2026-08-07 Principle 1: blind means blind, and the comparison happens once at T14
    The §9 numbers were consulted stage by stage on 2026-08-07 -- the rho_s scan,
    the ion template, the timing diagnostics -- against the plan's own first
    principle. It produced churn rather than progress: T10 promoted to critical
    path then demoted, a diffusion-vs-transport hypothesis raised then refuted a
    run later, a headline conclusion published then withdrawn.
    It is also uninterpretable by construction. A mismatch cannot be attributed to
    anything while T10, T12 and T13 are missing or stubbed, and the comparisons
    were run against targets from a different gas at a different drift field.
    Validate on INTERNAL physics inste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
2026-08-08 S2: transparency curve eps(E_amp/E_drift), production+6 smoke points
    All 6 scan solves pass S1-S5/G1-G3 (amp bulk constant at ~31008 V/cm,
    independent of E_drift as expected); the bench point (ratio 93.1) is
    the accepted production value 0.955. Curve is monotonic and saturating,
    the expected Micromegas shape: 0.990 at ratio 620 down to 0.547 at
    ratio 31 -- transparency drops as the drift field is pushed harder
    relative to the amp field, pulling more field lines onto the mesh
    wires instead of through the openings.
    [transparency_curve.csv]
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
